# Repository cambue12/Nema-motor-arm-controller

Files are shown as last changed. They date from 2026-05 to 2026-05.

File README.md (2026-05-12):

# Robotic Arm Controller

A 4-axis robotic arm with a parallel-gripper end effector, custom 3D-printed structure with planetary gearboxes, and a browser-based control interface that runs in real time over WebSerial.

Hero

## What's in this project

| Subsystem | Tech | Folder |
|---|---|---|
| **Mechanical** | NEMA 23 (shoulder) + 3× NEMA 17, custom 5:1 planetary gearboxes, 3D-printed structural parts | `cad/` |
| **Electronics** | Arduino UNO + CNC Shield + DM556 stepper driver | _diagrams in `docs/`_ |
| **Web Control App** | Single-file HTML, Three.js, WebSerial | `web/` |
| **iOS Hand-Tracking Bridge** | SwiftUI + ARKit + Vision + LiDAR | `ios-bridge/` |
| **WebSocket Relay** | Python `websockets` library | `server/` |

## Joints

| Joint | Motor | Driver | Microsteps | Gear | Range |
|---|---|---|---|---|---|
| **Base (X)** | NEMA 17 | A4988 (CNC shield) | 1/8 (2 jumpers) | 1:1 | ±180° |
| **Shoulder (Y)** | NEMA 23 | DM556 | 1/8 | 5:1 planetary | ±90° |
| **Elbow (Z)** | NEMA 17 | A4988 (CNC shield) | full step (no jumpers) | 5:1 planetary | ±140° |
| **Wrist (A)** | NEMA 17 | A4988 (CNC shield) | full step (no jumpers) | 1:1 | ±720° |
| **Claw** | (geared servo) | — | — | — | 0–100% open |

## Quick start

### 1. Run the web control app

```bash
cd web
python3 -m http.server 8888
```

Open `http://localhost:8888/armctl.html` in Chrome (Chrome only — WebSerial is required).

The simulator runs without any hardware connected. To talk to the real arm, plug the Arduino in via USB and click **CONNECT**.

### 2. (Optional) iPhone hand tracking

Build the `ios-bridge/ARHandBridge.swift` project in Xcode (see [`ios-bridge/README.md`](ios-bridge/README.md)). The phone uses LiDAR + Vision to track your hand and streams 3D coordinates over a Python WebSocket relay (`server/relay.py`) to the web app.

## Documentation

- [`docs/HARDWARE.md`](docs/HARDWARE.md) — physical setup and wiring
- [`docs/SOFTWARE.md`](docs/SOFTWARE.md) — how the control app works
- [`docs/SAFETY.md`](docs/SAFETY.md) — the layered safety system
- [`docs/BOM.csv`](docs/BOM.csv) — bill of materials

## Project status

Active development. Mechanical V4 is the current production assembly.

## License

MIT — see [LICENSE](LICENSE).

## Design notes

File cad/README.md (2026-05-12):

# CAD & 3D-Printed Parts

## Files

- **`RoboticArm.f3d`** — Fusion 360 source assembly (Arm Assembly V4). Open with Fusion 360 to edit components or export new STL files.
- **`stl/`** — exported STL meshes for 3D printing.

## Print order (recommended)

| # | File | Notes |
|---|---|---|
| 01 | `01_Base.stl` / `02_BaseV2.stl` | Dome/skirt base — needs supports under the flare |
| 03 | `03_BottomPlate.stl` | Bottom mounting plate |
| 04 | `04_TopPlate.stl` | Top of the rotating disc |
| 05 | `05_TopSupport.stl` | Shoulder column / motor housing |
| 06 | `06_FirstLink.stl` | Upper arm |
| 07 | `07_SecondLink.stl` | Forearm horn |
| 08 | `08_LinkToWrist.stl` | Wrist tube + face plate |
| 09 | `09_Gearbox_SunGear.stl` | Planetary sun gear (smaller) |
| 10 | `10_Gearbox_PlanetGear.stl` | Planetary planet gears (×4) |

## Print settings (suggested)

- **Material:** PLA+ for testing, PETG or ABS for final assembly
- **Layer height:** 0.2 mm
- **Infill:** 35% gyroid for structural parts, 100% for gears
- **Walls:** 4 perimeters minimum
- **Supports:** required for the dome base flare and any overhangs > 45°

## Gearbox

5:1 planetary reduction. The shoulder uses one of these driven by a NEMA 23 + DM556 driver; the elbow uses a smaller version driven by a NEMA 17. The web app's joint settings have `gr: 5.0` baked in for both joints.

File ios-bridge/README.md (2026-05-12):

# iPhone LiDAR Hand-Tracking Bridge

A SwiftUI app that uses ARKit + Vision + LiDAR to detect the user's hand in 3D space and stream wrist coordinates over a WebSocket to the web control app.

## Requirements

- iPhone with LiDAR (iPhone 12 Pro or newer Pro models)
- Xcode 15+
- iOS 16+ deployment target

## Setup

1. Open Xcode → **Create New Project** → **iOS App** (SwiftUI lifecycle)
2. Name it `ARHandBridge`
3. Replace `ContentView.swift` with the contents of `ARHandBridge.swift` from this folder
4. Delete the auto-generated `ARHandBridgeApp.swift` (the Swift file in this repo provides the `@main` struct)
5. In the project's **Info** tab, add `Privacy - Camera Usage Description` = "Hand tracking"
6. Plug your iPhone in, select it as the run target, hit ▶
7. Trust the developer certificate on the phone: **Settings → General → VPN & Device Management**

## Usage

1. Run `python3 server/relay.py` on your Mac
2. Find your Mac's local IP (System Settings → Wi-Fi → Details)
3. In the iPhone app, type the Mac's IP and tap **Connect**, then **Start AR**
4. In `armctl.html`, connect to `ws://localhost:8765` from the LiDAR section

## How it works

```
iPhone (ARKit + Vision)
   ↓ {x, y, z} JSON @ 30fps
WebSocket ws://MAC_IP:8765
   ↓ relay.py forwards to all clients
   ↓
armctl.html (browser, ws://localhost:8765)
   → solveIK(x, y, z)
   → MOVE commands over WebSerial
   → Arduino → DM556 / A4988 → motors
```

The phone reads the 2D wrist position via Vision's `VNDetectHumanHandPoseRequest`, samples the LiDAR depth at that pixel, and unprojects to 3D world coordinates using the camera intrinsics.

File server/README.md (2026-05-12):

# WebSocket Relay

Tiny broadcast relay: any message any client sends gets forwarded to all other connected clients. Lets the iPhone push hand-tracking coordinates to the browser without either of them having to act as a server.

## Setup

```bash
pip3 install websockets
python3 relay.py
```

Listens on `ws://0.0.0.0:8765`.

## How it's used

- The iPhone app connects out to your Mac on port 8765 and sends `{"x":...,"y":...,"z":...}` JSON frames at ~30Hz.
- The browser at `armctl.html` connects to `ws://localhost:8765` and receives the same frames.
- The relay just copies messages between connected sockets — it does not parse or validate anything.

## Why this exists

iOS doesn't allow apps to easily host TCP listeners that browsers can connect to. Reversing the connection direction (iPhone → Mac, Browser → Mac) sidesteps the problem entirely.

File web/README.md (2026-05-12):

# Web Control App (`armctl.html`)

Single-file browser app — HTML + Three.js + WebSerial. No build step.

## Running

```bash
python3 -m http.server 8888
```

Open `http://localhost:8888/armctl.html` in **Google Chrome** (WebSerial is Chrome-only).

You can also open the file directly with `file://`, but the camera-tracking and MediaPipe features will be blocked by the browser. Use the local server.

## Features

- **Live 3D simulation** of the arm via Three.js
- **WebSerial** to send `MOVE` commands to the Arduino over USB
- **Sliders + presets** for direct joint control
- **Activity macros** — Wave, Dance, Spin, Pick & Place, Sleep, Showcase, EXPO Demo, etc.
- **Hand tracking via webcam** (MediaPipe) — IK and per-finger control modes
- **WebSocket bridge** for receiving 3D coordinates from the iPhone LiDAR app
- **Layered safety system** — speed/accel profiles, per-command step caps, confirmation modals for big moves, panic-stop on spacebar

## Keyboard shortcuts

| Key | Action |
|-----|---|
| `Space` | EMERGENCY STOP |
| `Esc` | Cancel confirmation modal |

## Settings

Joint microstep / steps-per-rev / gear ratio settings live inside the SETTINGS panel. They default to:

| Joint | μstep | spr | gr |
|---|---|-----|----|
| Base (X) | 8 | 200 | 1.0 |
| Shoulder (Y) | 8 | 200 | 5.0 |
| Elbow (Z) | 1 | 200 | 5.0 |
| Wrist (A) | 1 | 200 | 1.0 |

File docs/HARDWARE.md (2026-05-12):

# Hardware

## Electronics

```
USB ───▶ Arduino UNO ──┬─▶ CNC Shield V3 ──┬─▶ A4988 (Base)     ──▶ NEMA 17
                       │                   ├─▶ A4988 (Elbow)    ──▶ NEMA 17 → 5:1 planetary
                       │                   └─▶ A4988 (Wrist)    ──▶ NEMA 17
                       └─▶ D12/D13 ─────────▶ DM556 ─────────────▶ NEMA 23 → 5:1 planetary
```

### Pin assignments (CNC Shield)

| Joint | Shield axis | Step pin | Dir pin | Microsteps |
|---|---|---|---|---|
| Base | X | D2 | D5 | 1/8 (MS1+MS2 jumpers) |
| Wrist | Y | D3 | D6 | full step (no jumpers) |
| Elbow | Z | D4 | D7 | full step (no jumpers) |
| Shoulder | A (D12/D13) | D12 | D13 | 1/8 (set on DM556) |

### DM556 dip switches (for NEMA 23 shoulder)

`SW1-SW4` set the current; `SW5-SW8` set microsteps.

For 1/8 microstepping (1600 steps/rev): `SW5=ON, SW6=OFF, SW7=ON, SW8=ON`.

## Mechanical

### Joint reductions

| Joint | Motor | Gearbox | Steps per joint degree |
|---|---|---|---|
| Base | NEMA 17 | direct (1:1) | 4.4 |
| Shoulder | NEMA 23 | planetary 5:1 | 22.2 |
| Elbow | NEMA 17 | planetary 5:1 | 2.8 |
| Wrist | NEMA 17 | direct (1:1) | 0.56 |

The high-resolution shoulder (22 steps/°) is what allows the heaviest joint to move smoothly.

The low-resolution wrist and elbow (0.56 / 2.8 steps/°) are acceptable because those joints are downstream — small angle errors there don't accumulate the way they do at the shoulder.

### Arm dimensions (mm)

- `L0 = 48` — base height
- `COL_H = 78` — column / shoulder pivot height above base top
- `L1 = 220` — upper arm length
- `L2 = 60` — forearm length
- `L3 = 140` — wrist horn + face plate length

Total reach (fully extended): `L1 + L2 + L3 = 420 mm`

## Power

- **24V DC** to the DM556 (the NEMA 23 needs the higher voltage)
- **12V DC** to the CNC Shield's Vmot pin (powers the A4988s)
- USB **5V** powers the Arduino logic

⚠️ Never share grounds across power supplies without isolation. The DM556's PUL/DIR/ENA inputs are opto-isolated — wire them with their own + and − pairs from the Arduino.

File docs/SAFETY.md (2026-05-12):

# Safety

These motors are strong — especially the NEMA 23 with the 5:1 planetary gearbox at the shoulder. A runaway move can break printed parts, snap fingers, or rip cables out. The safety system is designed to fail closed.

## Hard limits (hardcoded — no UI override)

- **80 steps per single MOVE command** — the firmware can't be told to do more in one shot.
- **Joint angle clamps** — `Math.max(min, Math.min(max, val))` on every `setJoint` call.
- **Sync interval pauses while sliders are being dragged** — prevents buffer flooding.

## Soft limits (UI-controllable)

- **Safety profile selector** in the bottom bar:
  - `SAFE` (default) — speed 60, accel 30
  - `NORMAL` — speed 140, accel 80
  - `FAST` — speed 240, accel 160
- The selected profile is sent to the firmware via `SET SPEED` / `SET ACCEL` on every connect and re-applied after E-Stop is cleared.

## Confirmation gates

The big modal asks "Are you sure?" before:

- Applying any **preset** that moves a joint by more than 35°
- Releasing any **slider** more than 35° away from the current position

## Panic stops

| Trigger | Effect |
|---|---|
| `SPACEBAR` | `STOP ALL` + `DISABLE ALL`, drivers off, `lastSentSteps` resync, motion banner cleared |
| Red **STOP** button | Same as spacebar |
| **STOP ALL** in the bottom bar | Sends `STOP ALL` and resyncs the step tracking |
| Disconnecting USB | Drivers de-energise, arm holds via gear friction |

## What happens during E-Stop

1. All running activities/test moves/camera modes are stopped immediately
2. `lastSentSteps[]` is snapped to the current target so when E-Stop clears, the system doesn't re-send a queue of buffered moves
3. `STOP ALL` and `DISABLE ALL` go to the firmware
4. Toast notification appears
5. UI reflects E-Stop state until manually cleared

## After clearing E-Stop

Drivers stay OFF until you click **ENABLE** again. The safety profile is re-pushed to the firmware. You'll need to manually re-enable drivers before any movement.

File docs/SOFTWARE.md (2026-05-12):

# Software Architecture

## How a click becomes a motor step

```
User drags slider
   ↓ input event
changeJoint(key, value)        ← updates J[key] (the simulation target)
   ↓ updates 3D model + UI

Slider released (change event)
   ↓
sliderReleased(key)
   ↓
sendJointHW(key)               ← computes integer-step delta from lastSentSteps
                                 → caps to MAX_STEPS_PER_CMD (80)
                                 → "MOVE A 22\r\n" out the WebSerial port
   ↓
Arduino firmware
   ↓
DM556 / A4988
   ↓
Motor turns

(in parallel)
100 ms sync interval ──→ sendAllJointsHW()  ← chunks any remaining delta to hardware
                                              until lastSentSteps == jointTargetSteps
```

## Forward kinematics

`computeFK(j)` uses the same convention as the Three.js scene graph:

- `rotGroup.rotation.y = -j.X`  (base)
- `upperArmGroup.rotation.x = +j.Y`  (shoulder)
- `forearmGroup.rotation.x = +j.Z`  (elbow)
- `wristGroup.rotation.y = +j.A`  (wrist roll)

World direction of the upper arm is:
```
armDir = (-sin(sa)*sin(ba), cos(sa), +sin(sa)*cos(ba))
```

EE position is then `shoulder + L1·armDir + (L2+L3)·foreDir`.

## Inverse kinematics

`solveIK(tx, ty, tz, fallbackBase)` is a 2-link planar IK using the law of cosines:

1. `R = sqrt(tx² + tz²)` — projected distance in the floor plane
2. `Ht = ty - shoulderPivotY`
3. `baseDeg = atan2(-tx, tz)` (matches the FK convention above)
4. Clamp `d = sqrt(R² + Ht²)` to the reachable sphere radius `(L1 + L2 + L3) * 0.97`
5. Elbow: `acos((d² - L1² - L23²) / (2·L1·L23))`
6. Shoulder: `atan2(R, Ht) − atan2(L23·sin(elbow), L1 + L23·cos(elbow))`

A singularity guard kicks in when the target is within 25mm of the vertical axis — it falls back to the previous base angle and blends `R` smoothly to avoid the arm spinning wildly.

## Safety system

Layered defences against the strong NEMA 23 / planetary-geared joints:

1. **`MAX_STEPS_PER_CMD = 80`** — every single MOVE command is capped. Big simulation jumps get chunked across the 100ms sync ticks.
2. **Safety profiles** (`SAFE / NORMAL / FAST`) push conservative `SET SPEED` and `SET ACCEL` to the firmware on connect.
3. **Confirmation modal** for any preset or slider release that would move a joint by more than 35°.
4. **Per-axis motion tracking** — banner appears at top showing which axes are still moving.
5. **`SPACEBAR` panic stop** — sends `STOP ALL`, disables drivers, snaps `lastSentSteps` to current `J` so the queue can't ambush you.
6. **`STOP ALL` resync** — local `lastSentSteps` re-sync prevents the sync loop from re-firing the moves the firmware just discarded.
7. **Slider drag pause** — the 100ms sync interval pauses while any slider is being dragged, preventing command queue buildup.

## Activities

Defined as keyframe arrays in `ACTIVITIES`. Each keyframe is `{X, Y, Z, A, CLAW, d}` where `d` is the duration in seconds for the smooth transition into that pose. `loops:true` activities cycle indefinitely.

```javascript
{name:'wave', label:'Wave', loops:false, kf:[
  {X:40, Y:55, Z:30, A:0,   CLAW:20, d:.7},
  {X:40, Y:55, Z:30, A:70,  CLAW:40, d:.3},
  {X:40, Y:55, Z:30, A:-70, CLAW:20, d:.3},
  ...
]}
```

The interpolation uses a smoothstep curve (`ssf(t) = t*t*(3 - 2*t)`) for natural ease-in/ease-out.

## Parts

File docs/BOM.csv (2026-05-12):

Name | Product Name | Description | Category | Type | Quantity | Estimated Cost | Total Cost | URL
Main Controller | ESP32-WROOM-32 Development Board | Main microcontroller for arm control and servo PWM generation. | electrical | mcu | 1 | 10.99 | 10.99 | https://www.amazon.com/s?k=ESP32+development+board
5V Buck Converter | LM2596 DC-DC Buck Converter Module | Steps down input voltage to stable 5V for servos and MCU. | electrical | power | 1 | 3.50 | 3.50 | https://www.amazon.com/s?k=LM2596+buck+converter
Base Rotation Servo | SG90 Micro Servo Motor | Servo for controlling the arm's base rotation. | electrical | actuator | 1 | 4.00 | 4.00 | https://www.amazon.com/s?k=SG90+micro+servo
Shoulder Joint Servo | SG90 Micro Servo Motor | Servo for controlling the shoulder joint's articulation. | electrical | actuator | 1 | 4.00 | 4.00 | https://www.amazon.com/s?k=SG90+micro+servo
Elbow Joint Servo | SG90 Micro Servo Motor | Servo for controlling the elbow joint's articulation. | electrical | actuator | 1 | 4.00 | 4.00 | https://www.amazon.com/s?k=SG90+micro+servo
Wrist Joint Servo | SG90 Micro Servo Motor | Servo for controlling the wrist joint's articulation. | electrical | actuator | 1 | 4.00 | 4.00 | https://www.amazon.com/s?k=SG90+micro+servo
Gripper Servo | SG90 Micro Servo Motor | Servo for opening and closing the end-effector gripper. | electrical | actuator | 1 | 4.00 | 4.00 | https://www.amazon.com/s?k=SG90+micro+servo
Robot Arm Base Plate |  | Base plate for the robot arm, providing a stable foundation. | mechanical | structural | 1 | 5.00 | 5.00 | https://www.amazon.com/s?k=acrylic+sheet+100x80x3mm
M3 Screws | M3x8mm Phillips Head Screws |  | mechanical | misc | 20 | 0.05 | 1.00 | https://www.amazon.com/s?k=m3x8mm+screws
M3 Nuts | M3 Hex Nuts |  | mechanical | misc | 20 | 0.03 | 0.60 | https://www.amazon.com/s?k=m3+nuts
M3 Standoffs | M3x10mm Brass Hex Standoffs |  | mechanical | misc | 4 | 0.10 | 0.40 | https://www.amazon.com/s?k=m3x10mm+brass+standoffs
Lower Arm Link |  | First link of the robot arm, connects to the base servo. | mechanical | 3d_printed | 1 | 0.50 | 0.50 | N/A
Upper Arm Link |  | Second link of the robot arm, connects two servos. | mechanical | 3d_printed | 1 | 0.40 | 0.40 | N/A
Wrist Link |  | Final link before the end effector. | mechanical | 3d_printed | 1 | 0.30 | 0.30 | N/A
Base Servo Mount |  | Mount for the base servo to attach to the base plate. | mechanical | 3d_printed | 1 | 0.25 | 0.25 | N/A
Link Servo Mount |  | Mount for attaching a servo to an arm link. | mechanical | 3d_printed | 2 | 0.20 | 0.40 | N/A
Gripper End Effector |  | Simple two-finger gripper for light object manipulation. | mechanical | 3d_printed | 1 | 0.75 | 0.75 | N/A
Microcontroller Mount |  | Mounting bracket for the ESP32 or Arduino Nano. | mechanical | 3d_printed | 1 | 0.30 | 0.30 | N/A

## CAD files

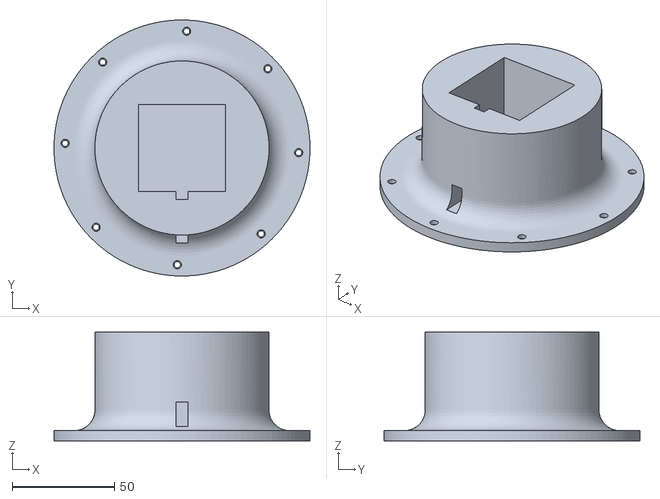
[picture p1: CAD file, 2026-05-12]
cad/stl/01_Base.stl
125.0 x 125.0 x 53.0

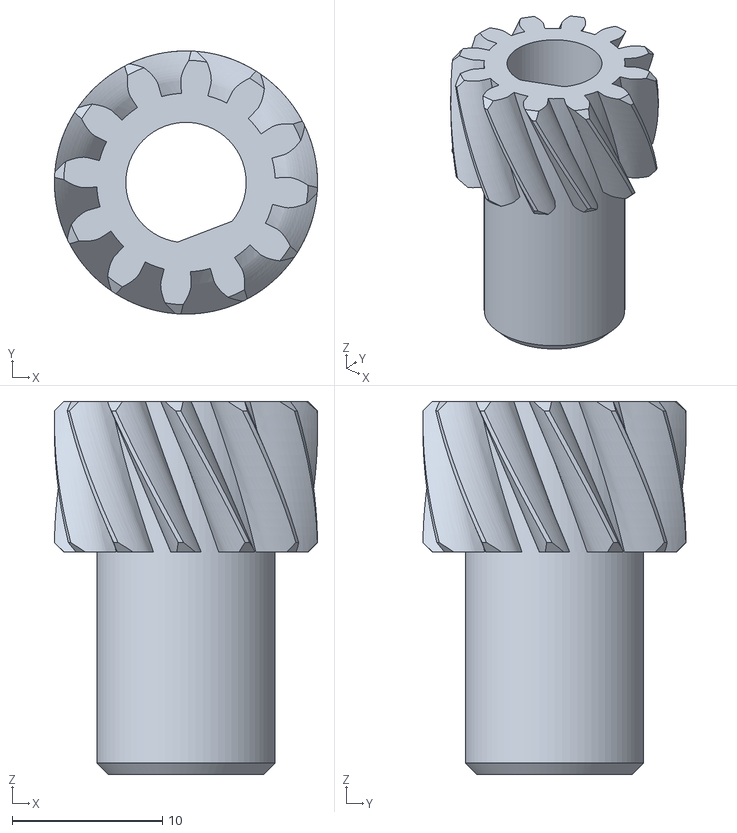
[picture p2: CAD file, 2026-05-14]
makerworld-stls/gears/Sun_Gear.stl
17.5 x 17.5 x 24.8

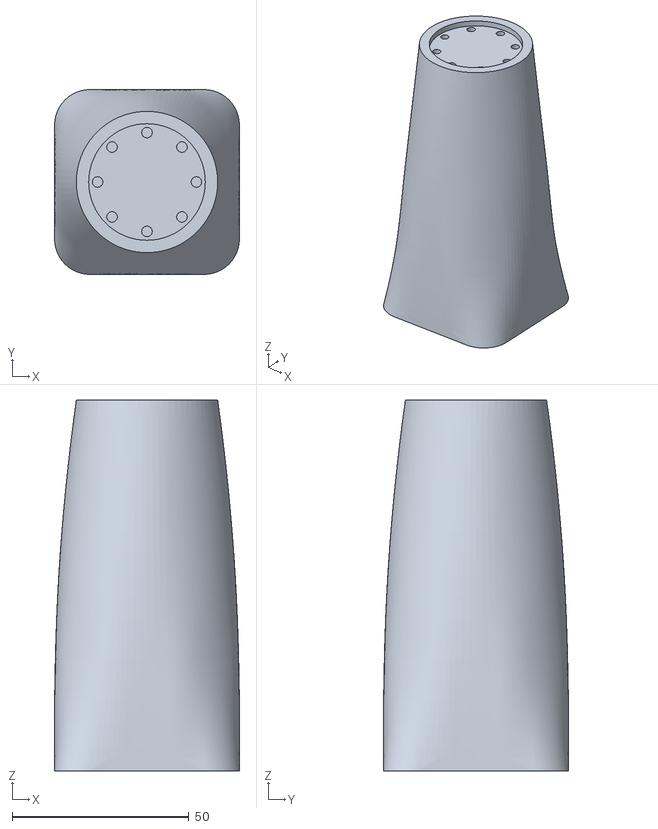
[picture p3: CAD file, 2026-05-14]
makerworld-stls/Link_to_Wrist.stl
52.5 x 52.5 x 105.0

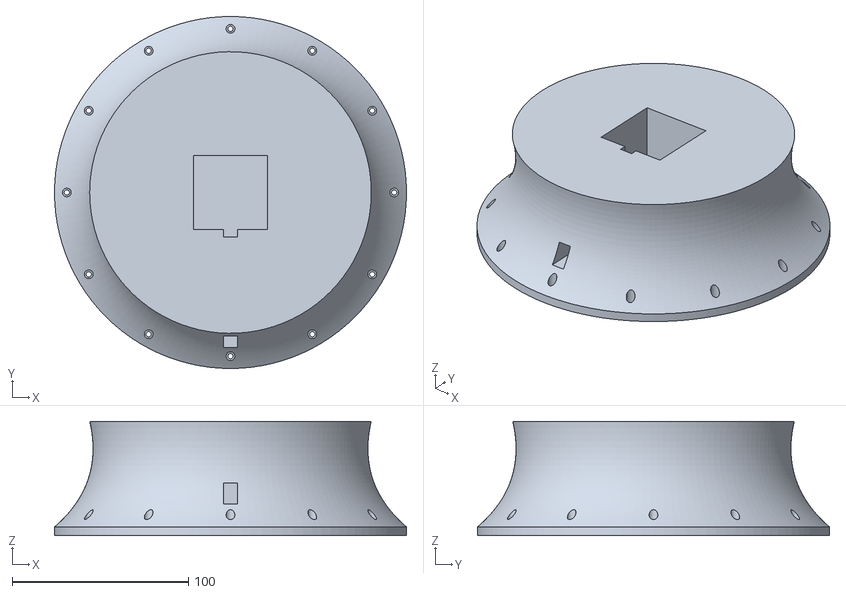
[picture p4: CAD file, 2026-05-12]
cad/stl/02_BaseV2.stl
200.0 x 200.0 x 65.0

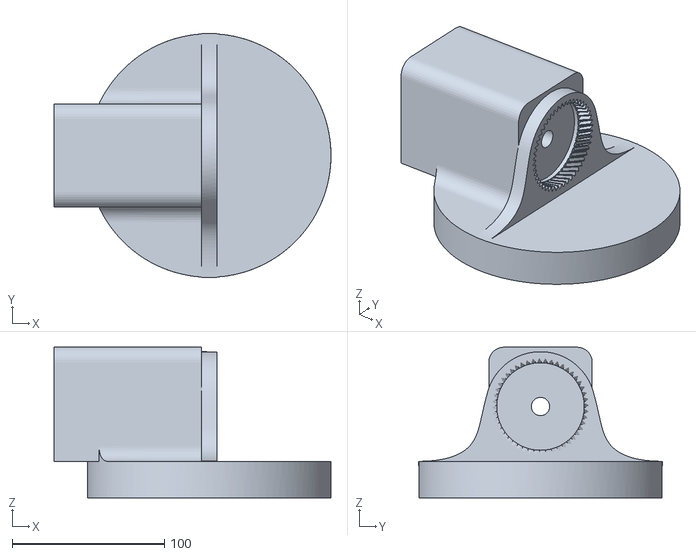
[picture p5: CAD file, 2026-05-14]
makerworld-stls/BASE_REMAKE.stl
182.0 x 160.0 x 99.0

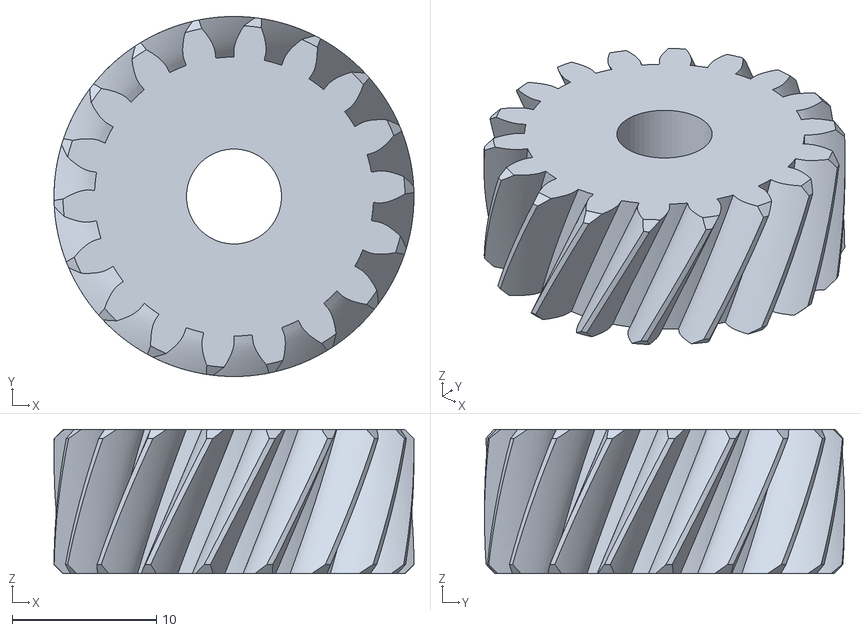
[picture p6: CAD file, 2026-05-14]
makerworld-stls/gears/Planet_Gear.stl
25.0 x 25.0 x 10.0

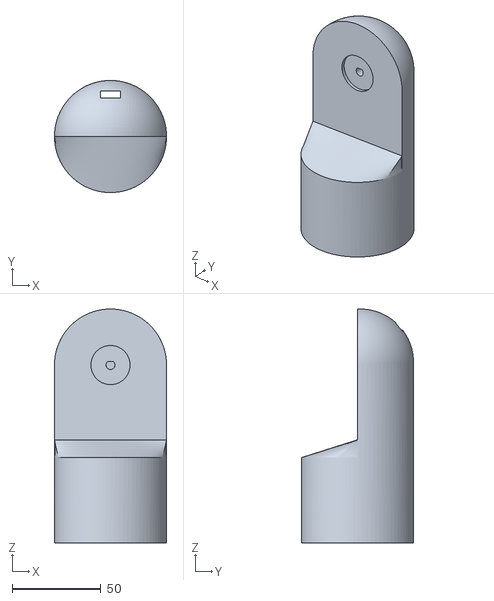
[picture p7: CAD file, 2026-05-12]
cad/stl/07_SecondLink.stl
63.0 x 63.0 x 131.5

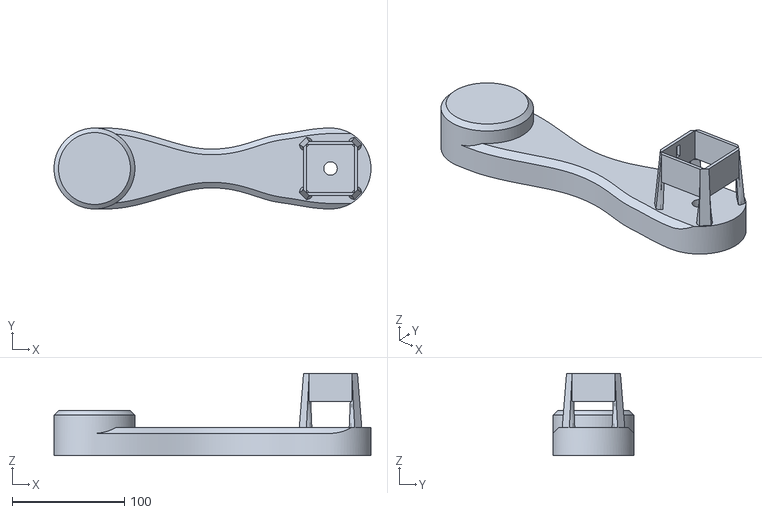
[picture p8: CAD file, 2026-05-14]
makerworld-stls/First_Length.stl
282.0 x 72.0 x 73.1

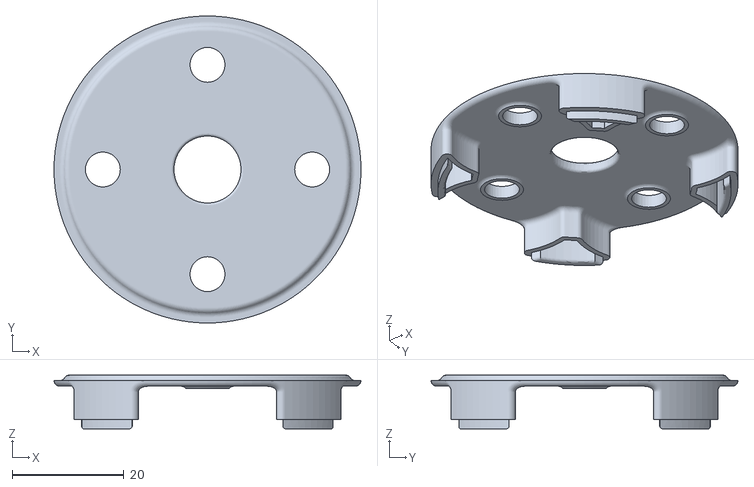
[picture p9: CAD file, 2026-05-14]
makerworld-stls/BOTTOM_PLATE.stl
55.0 x 55.0 x 9.65

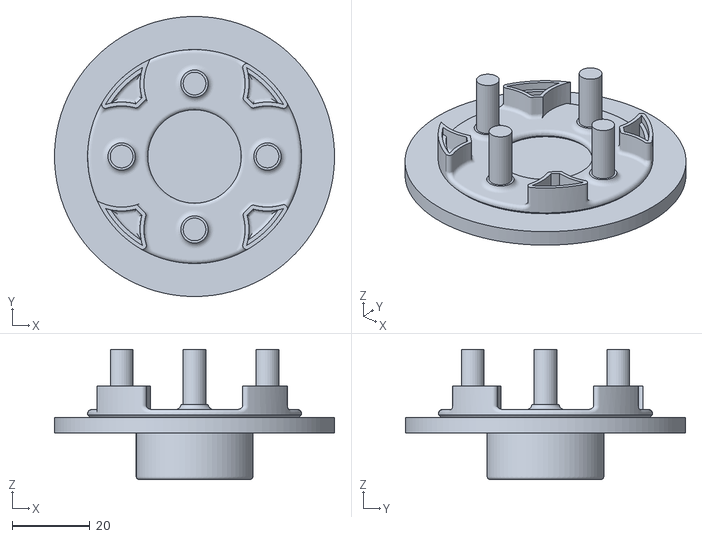
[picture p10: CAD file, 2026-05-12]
cad/stl/04_TopPlate.stl
72.0 x 72.0 x 33.4

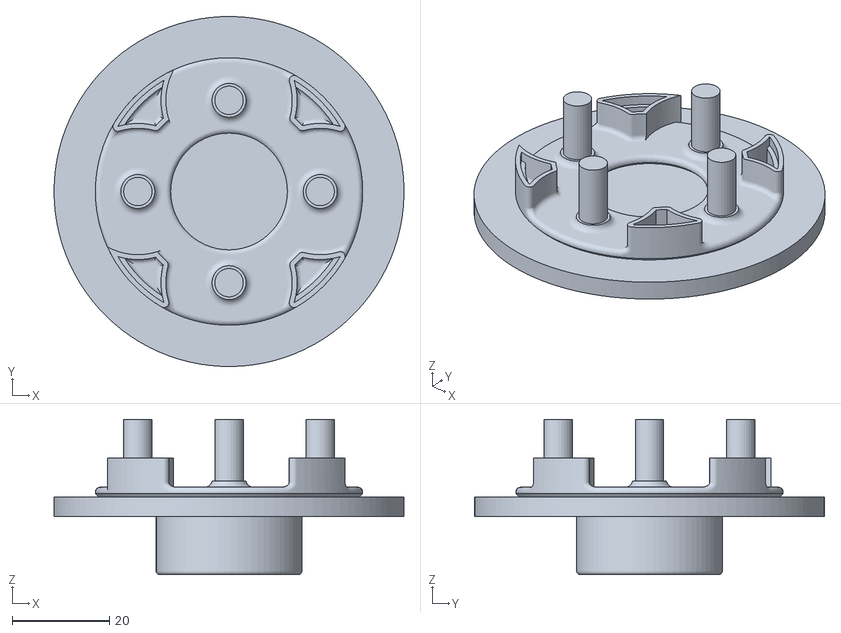
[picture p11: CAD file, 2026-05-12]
cad/stl/05_TopSupport.stl
72.0 x 72.0 x 31.9

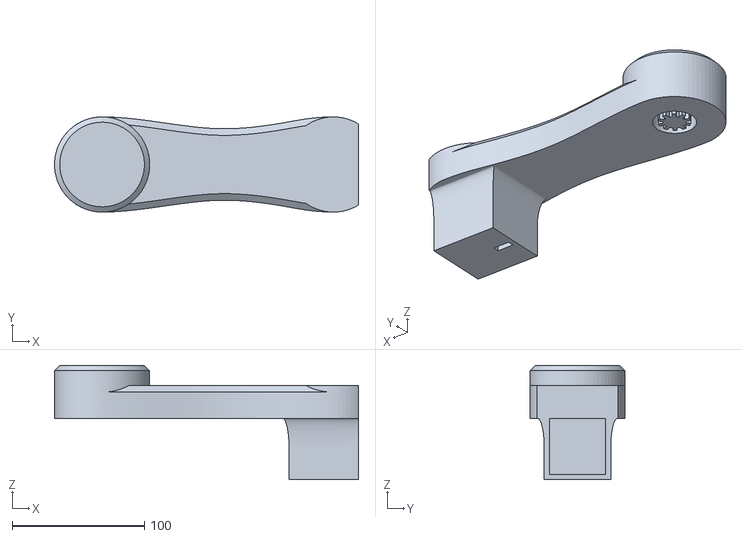
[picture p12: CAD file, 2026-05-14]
makerworld-stls/SECOND_LENGTH_V2.stl
229.9 x 72.0 x 86.3

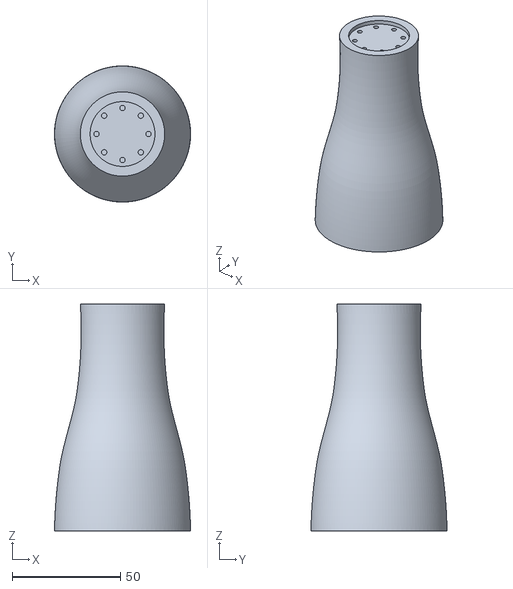
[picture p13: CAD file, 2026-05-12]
cad/stl/08_LinkToWrist.stl
63.0 x 63.0 x 105.0

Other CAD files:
cad/stl/09_Gearbox_SunGear.stl
makerworld-stls/Second_Link.stl
makerworld-stls/TOP_PLATE.stl
cad/stl/10_Gearbox_PlanetGear.stl
cad/stl/03_BottomPlate.stl
cad/RoboticArm.f3d
cad/stl/06_FirstLink.stl
makerworld-stls/BASE_REMAKE.f3d
makerworld-stls/BOTTOM_PLATE.f3d
makerworld-stls/First_Length.f3d
makerworld-stls/Link_to_Wrist.f3d
makerworld-stls/SECOND_LENGTH_V2.f3d
makerworld-stls/Second_Link.f3d
makerworld-stls/TOP_PLATE.f3d
makerworld-stls/gears/Planet_Gear.f3d
makerworld-stls/gears/Sun_Gear.f3d

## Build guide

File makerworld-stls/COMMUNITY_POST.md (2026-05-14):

Hey everyone — new to MakerWorld! I'm a student working through engineering and I've been building this 4-axis robot arm for the past few months. NEMA 23 + custom 5:1 planetary gearbox at the shoulder, three NEMA 17s for the other joints, parallel gripper. Controlled live in a browser over USB.

Source (app + firmware): github.com/cambue12/Nema-motor-arm-controller

Heads up: Second Link and Link to Wrist are the latest revisions but haven't been printed yet. Hope you find it interesting! 🤖

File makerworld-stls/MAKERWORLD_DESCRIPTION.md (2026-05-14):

# 4-Axis Robotic Arm with Browser Control

A fully working 4-axis robotic arm with a parallel-gripper end effector — driven by a NEMA 23 with a custom 5:1 planetary gearbox at the shoulder, three NEMA 17s for the base, elbow and wrist, and controlled live in a browser over USB through a custom Three.js + WebSerial app.

This upload is the **mechanical structure** — the printable parts of the arm. Wiring, firmware and the browser control app are all open-source and linked below.

> ⚠️ **Build status note** — the **Second Link** and **Link to Wrist** parts in this upload are the latest design revisions and have **not yet been printed and assembled** at the time of this post. All other parts are printed and in active use. I'm uploading the design as-is so others can start their own builds; printability has been validated in the slicer for both unprinted parts.

---

## What's printable

| Part | Notes |
|---|---|
| **BASE REMAKE** | Dome / skirt base with bolt circle. Mounts to a flat surface with M5 bolts. |
| **BOTTOM PLATE** | Lower plate of the planetary gearbox housing. ×2 needed (one per gearbox: shoulder + elbow). |
| **TOP PLATE** | Upper plate of the planetary gearbox housing. ×2 needed. |
| **First Length** | Upper arm — from shoulder pivot to elbow. |
| **Second Link** ⚠️ | Forearm transition piece. *Not yet print-validated.* |
| **SECOND LENGTH (V2)** | Forearm horn — the long tapered cone. |
| **Link to Wrist** ⚠️ | Wrist tube + face plate where the gripper bolts on. *Not yet print-validated.* |

The **planetary gears** themselves (sun + planets) are deliberately **not in this upload** — they'll be in a separate gearbox post so people can mix-and-match gear ratios.

## Print settings (recommended)

- **Material:** PETG or ABS for structural rigidity. PLA+ works for testing but the shoulder yoke takes real load.
- **Layer height:** 0.2 mm
- **Walls:** 4 perimeters minimum
- **Infill:** 35–40% gyroid for structural parts, 100% for the gearbox plates
- **Supports:** required under the dome flare on `BASE REMAKE` and overhangs > 45°
- **Orientation:** print everything with the smallest face down except the dome — flip that so the bolt rim is up

## Hardware bill of materials

### Motors & drivers
- 1× **NEMA 23** stepper (shoulder)
- 3× **NEMA 17** stepper (base, elbow, wrist)
- 1× **DM556** standalone stepper driver (drives the NEMA 23)
- 1× **Arduino UNO + CNC Shield V3** (3× onboard A4988 drivers for the NEMA 17s)
- 1× 24V DC power supply (for the DM556)
- 1× 12V DC power supply (for the CNC shield)

### Mechanical
- 8× planetary planet gears + 2× sun gears (printed — separate upload)
- M3 bolts, nuts, washers throughout
- 608 bearings for the rotating disc
- M5 bolts for floor mounting

### Optional
- iPhone 12 Pro or newer (for LiDAR hand-tracking control)

## Joint specs

| Joint | Motor | Gearbox | Range | Microsteps |
|---|---|---|---|---|
| Base | NEMA 17 | direct (1:1) | ±180° | 1/8 |
| Shoulder | NEMA 23 | 5:1 planetary | ±90° | 1/8 (DM556) |
| Elbow | NEMA 17 | 5:1 planetary | ±140° | full step |
| Wrist | NEMA 17 | direct (1:1) | ±720° | full step |

Total reach: ~420 mm fully extended.

## Software

The browser-based control app, iPhone LiDAR hand-tracking bridge, WebSocket relay, and full source for the Arduino firmware are all open-source on GitHub:

🔗 **[github.com/cambue12/Nema-motor-arm-controller](https://github.com/cambue12/Nema-motor-arm-controller)**

Features include:
- Live 3D simulation in the browser (Three.js)
- Real-time WebSerial control over USB
- Webcam hand-tracking (MediaPipe) — IK and per-finger control modes
- iPhone LiDAR hand-tracking (ARKit + Vision)
- Activity macros: Wave, Dance, Pick & Place, Showcase, EXPO Demo, etc.
- Layered safety system with confirmation modals and panic-stop

## Customisable parameters

Each `.f3d` file has a `Scale` parameter exposed to MakerWorld's customiser — bump it up or down to print the arm at a different size. (Note: hardware will need to be matched accordingly.)

## Print order recommendation

1. `BASE REMAKE`
2. `BOTTOM PLATE` (×2)
3. `TOP PLATE` (×2)
4. `First Length`
5. `SECOND LENGTH (V2)`
6. `Second Link` ⚠️ unprinted reference
7. `Link to Wrist` ⚠️ unprinted reference

## Credits & License

Designed in Fusion 360. MIT-licensed source on GitHub.

If you build one, please share photos in the print log or tag me — I'd love to see other people's takes on it. Pull requests welcome on the GitHub repo too if you find improvements.

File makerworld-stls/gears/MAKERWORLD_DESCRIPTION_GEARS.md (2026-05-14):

5:1 Planetary Gearbox — Sun & Planet Gears (NEMA 17 / NEMA 23)

A printable 5:1 reduction planetary gear set designed for high-torque robotic and mechanical applications. Includes the sun gear (driven by the motor) and the planet gears (4 needed for one gearbox stage). Pair with a printed ring gear and your own housing to build a complete planetary reduction.

These are the gears that drive the shoulder and elbow joints of my 4-axis robot arm — the shoulder runs a NEMA 23 through this reduction and is strong enough to lift several hundred grams at full extension.

Suggested model name

5:1 Planetary Gearbox Gears — Sun & Planet (NEMA 17 / 23 Compatible)

Or if you want something punchier, you could try:
Printable 5:1 Planetary Gear Set — Robot Arm Gearbox
High-Torque 5:1 Planetary Reduction (Sun + Planet Gears)
5:1 Planetary Gears for NEMA Stepper Motors

What's included

Sun_Gear (STL and F3D) — Centre driver gear that mounts on the motor shaft. Print 1 per gearbox.
Planet_Gear (STL and F3D) — Outer planet gear that rides between the sun and ring. Print 4 per gearbox.

Not included yet: the ring gear and housing. Those come with my full robot arm upload, or you can design your own to match.

Specs

Reduction ratio: 5 to 1
Module (gear tooth size): 1.25 mm
Sun gear: small centre gear, mounts to motor shaft
Planet gears: 4 needed, ride between sun and ring
Centre bore: 5.0 mm (suits common NEMA shaft adapters; adjustable in the customiser)

Customisation

The F3D files have these parameters exposed to the MakerWorld customiser, so you can tweak them before downloading:

Scale (default 1.0) — uniform scale multiplier
Tolerance (default 0.2 mm) — print clearance between meshing teeth; bump up if your printer is tight
BoreDiameter (default 5.0 mm) — centre bore diameter for motor shaft fit
modulus (default 1.25 mm) — gear module; change at your own risk since it must match the ring gear

Print settings

Material: PETG strongly recommended. PLA wears out fast under load. ABS works if you've got the chamber for it.
Layer height: 0.16 mm (finer is better for tooth surface finish)
Walls: 4 perimeters
Infill: 100 percent — these gears take real load
Supports: none needed if printed flat

What you'll need to assemble a complete gearbox

1 printed sun gear (this upload)
4 printed planet gears (this upload)
1 ring gear (printed; use your own or wait for my full release)
1 housing with planet carrier (printed)
5 M3 shoulder bolts or 5mm dowel pins for planet axles
1 thrust washer or bearing on the output shaft

Application

Designed for the shoulder and elbow joints of a 4-axis robot arm I'm building. The full project (browser control app, CAD, Arduino firmware, full BOM) is open-source on GitHub:

github.com/cambue12/Nema-motor-arm-controller

Also good for:
3D-printer extruder reductions
Telescope drive trains
Camera slider gearboxes
Any project where you want significant torque multiplication out of a NEMA stepper

Notes

The 5 to 1 ratio is the standard single-stage planetary output. If you want higher reduction (25 to 1, 125 to 1) you can stack stages — same gears, just chain the carrier output of one stage into the sun input of the next.

These print best in PETG with 100 percent infill. I tried PLA first and they wore out within a few hours of testing under load. PETG has held up indefinitely so far.

Tooth face finish matters. Print at 0.16 mm or thinner if you can. Sanding the teeth lightly with 400-grit afterward dramatically reduces noise.

Credits and License

Designed in Fusion 360. MIT licensed.

If you build a gearbox with these, drop a print log photo or tag me — would love to see other applications.

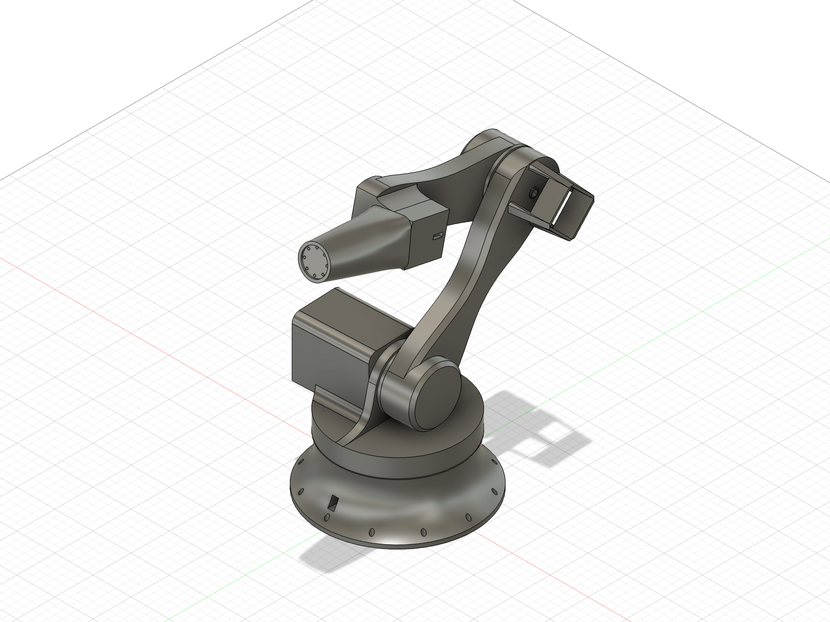
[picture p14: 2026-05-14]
makerworld-stls/cover_4x3.png

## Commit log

2026-05-12 Initial commit: full project — web app, iOS bridge, relay, CAD, docs
    - web/armctl.html: Three.js + WebSerial control app with safety system,
    IK/finger camera modes, EXPO Demo and other activities
    - ios-bridge/ARHandBridge.swift: SwiftUI ARKit + Vision + LiDAR hand tracking
    - server/relay.py: WebSocket broadcast relay
    - cad/RoboticArm.f3d: Fusion 360 source (Arm Assembly V4)
    - cad/stl/: 3D-printable parts (base, links, gearbox)
    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
    [01_Base.stl, 02_BaseV2.stl, 03_BottomPlate.stl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]
2026-05-14 Competition-ready polish: bug fixes, safety hardening, UX improvements
    Bug fixes
    - Fix undefined refHandSize → lastHandSize typo in toggleCameraControl
    - Fix lastSentSteps drift: only advance when capped delta is non-zero
    - Fix inverted slider-release confirmation logic (was firing wrong branch)
    - Fix camera frame loop memory leak (track + cancel requestAnimationFrame)
    - Add null-guards to stopCamera, toggleFingerMode, stopFingerMode
    - Cap console log to 500 lines to prevent unbounded DOM growth
    Safety
    - E-Stop now triggers a full-screen overlay so its state is unmistakable
    - E-Stop overlay has its own CLEAR button with conservative-profile re-arm
    - Spacebar panic stop hardened: ignores e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
2026-05-14 Add MakerWorld upload assets (STL + F3D + descriptions)
    Bundles all assets used for the MakerWorld submission so the repo
    is the single source of truth for the project.
    - 7 STL files for the major arm parts (base, plates, links, horn,
    wrist tube)
    - 7 matching F3D files with favorited customisation parameters
    (Scale, WallThickness, Tolerance, BoltHoleDia)
    - gears/ subfolder with Sun + Planet gear STL/F3D for separate
    gearbox listing
    - cover_4x3.png hero render for the model page
    - MAKERWORLD_DESCRIPTION.md and COMMUNITY_POST.md (under 500 chars)
    as the canonical text submitted to MakerWorld
    - gears/MAKERWORLD_DESCRIPTION_GEARS.md for the gearbox listing
    Note: Second Link and Link to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
    [BASE_REMAKE.f3d, BASE_REMAKE.stl, BOTTOM_PLATE.f3d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]
